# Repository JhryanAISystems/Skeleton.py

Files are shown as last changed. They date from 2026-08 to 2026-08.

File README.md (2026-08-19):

# Skeletonpy

Control software for an animatronic Halloween skeleton running on a Raspberry
Pi 4 Model B (4GB). It tracks faces with a camera, syncs the jaw to microphone
volume, switches between a calm "Host" and a jump-scare "Trickster"
personality, and speaks via pre-recorded lines and offline text-to-speech.

For the physical build (parts list, wiring, 3D-printed mounts, OS setup),
see [BUILD_GUIDE.md](BUILD_GUIDE.md). This README covers the software.

> **Note on hardware history:** this project originally targeted the
> Raspberry Pi Zero 2 W. Due to a prolonged supply shortage, the board was
> switched to a Pi 4 Model B (4GB). The Pi 4's larger footprint means it no
> longer fits inside the skull — it now lives in a separate torso/ribcage
> enclosure, connected to the skull's camera, servos, and LEDs by extended
> cables. The software stack is unchanged by this swap.

## How it works

`main.py` builds all hardware modules and wires them into a single
`BehaviorManager`, then runs a non-blocking control loop at
`CONFIG.timing.loop_hz` (~15 Hz):

1. `BehaviorManager.tick()` — polls triggers, updates head/jaw servo targets
   from vision/audio, and advances eye brightness.
2. `BehaviorManager.maybe_speak()` — occasionally queues a spoken line.

Every hardware-facing module (camera, mic/speaker, servos, LEDs, knock and
proximity sensors) follows the same pattern: a real backend using the actual
library (`picamera2`, `sounddevice`, `gpiozero`, ...), and a mock backend
that's auto-selected when the real one fails to import or initialize. This
means the exact same code runs on the Pi and on a dev laptop with no flags
or config changes.

### Personality state machine (`behavior.py`)

- **HOST** (default): amber, steady eyes; slower tracking/servo easing.
- **TRICKSTER**: red, flickering eyes; snappier tracking/servo easing.
- Switches to TRICKSTER on a loud noise, a knock, or someone getting within
  `CONFIG.proximity.trigger_distance_ft`. Auto-reverts to HOST after
  `CONFIG.timing.trickster_timeout_s` of no new triggers. A cooldown
  (`CONFIG.timing.mode_switch_cooldown_s`) prevents rapid re-triggering.

## Key files

| File | Responsibility |
|---|---|
| [main.py](main.py) | Entry point; builds the `BehaviorManager` and runs the control loop or `--test` smoke test |
| [behavior.py](behavior.py) | HOST/TRICKSTER state machine; knock and proximity sensor backends |
| [vision.py](vision.py) | Camera capture + Haar-cascade face tracking → head angle & closeness |
| [servo.py](servo.py) | Head/jaw servo control with eased (smoothed) motion |
| [audio.py](audio.py) | Mic amplitude sensing (jaw sync, loud-noise trigger) + non-blocking playback/TTS |
| [led.py](led.py) | Eye LED brightness, flicker, and Host/Trickster color state |
| [config.py](config.py) | All tunable parameters: GPIO pins, servo limits, thresholds, timing, audio line sets |
| [script_lines.py](script_lines.py) | Spoken-line content (guest lines, event lines, monologues) — kept separate from `config.py`. **Not tracked in this repo** — contains personalized guest content, kept local-only. |
| [generate_audio.py](generate_audio.py) | One-time offline script (run on a dev machine, not the Pi) that batch-generates MP3s via the ElevenLabs API from `script_lines.py` |
| `*.scad` | OpenSCAD source for 3D-printed mounts (see `BUILD_GUIDE.md` Part 4) |

## Setup

```bash
python3 -m venv venv
source venv/bin/activate      # Windows: venv\Scripts\activate
pip install -r requirements.txt
```

On a dev machine without Pi hardware, only `opencv-python` and `numpy` are
strictly required to run — everything else falls back to a mock backend if
its library or hardware isn't available.

## Usage

```bash
python main.py --test              # mock-hardware smoke test, then exit
python main.py                     # live run (real hardware where available)
python main.py --log-level DEBUG   # verbose logging
```

To (re)generate spoken-line audio from `script_lines.py`:

```bash
pip install requests
setx ELEVENLABS_API_KEY "your-key-here"   # Windows; reopen the shell after
python generate_audio.py
```

This writes MP3s into `audio/`, resuming safely if interrupted (existing
files are skipped). Copy the resulting `audio/` folder onto the Pi —
`audio.py` only plays files by name, it does not call the API on-device.

## Configuration

All tunables live in [config.py](config.py) as frozen dataclasses grouped by
subsystem (`GPIOPins`, `ServoLimits`, `AudioConfig`, `VisionConfig`,
`ProximityConfig`, `TimingConfig`, `AudioLineConfig`), bundled under the
module-level `CONFIG` singleton. Defaults were originally tuned for the Pi
Zero 2 W's limited CPU (smaller camera frame, frame-skipped detection,
slower loop rate). On the Pi 4, these are conservative rather than
necessary — there's headroom to raise camera resolution or loop rate if
you want a snappier feel, but the defaults are left as-is since they
already work reliably.

## Gotchas

- `main.py --test` reports in its log output which backend (real or mock)
  was selected for each module — if something you've wired up shows "mock",
  that's the first thing to check. Note that on a non-Pi dev machine (e.g.
  Windows), `picamera2` and `gpiozero` are *expected* to fall back to mock —
  that's the graceful-degradation design working as intended, not a bug.
- `generate_audio.py` is meant to run once, off-Pi, before deployment — not
  as part of the live control loop.
- Jittery head tracking or unreliable low-light detection are tuned via
  `tracking_smoothing_host` and `detection_min_neighbors` in `config.py`
  (see `BUILD_GUIDE.md` Part 5, steps 3 and 5).
- Since the Pi 4 lives in the torso rather than the skull, cable runs from
  skull to torso are longer than the original Pi Zero 2 W design assumed —
  see `BUILD_GUIDE.md` Part 2.8 for routing notes.

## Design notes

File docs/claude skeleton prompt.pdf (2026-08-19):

SYSTEM ROLE:
You are an expert robotics/embedded-systems engineer specializing in Raspberry Pi animatronics: OpenCV face tracking, audio amplitude detection, servo control,
LED PWM, and behavior-driven state machines.

TASK:
Generate a complete, runnable Python 3.11+ codebase for a full-size animatronic Halloween skeleton, split across the modules below. Output all files in one
response with clear file-path headers. No placeholders, no TODOs — every function must have working example logic (using mocked hardware where real hardware is unavailable).

──────────────────────────────
HARDWARE ASSUMPTIONS (state these as comments in config.py) ──────────────────────────────
- Raspberry Pi 4/5, Raspberry Pi Camera Module (picamera2)
- MG996R servo ×2 (head pan, jaw) via PWM (gpiozero or pigpio — pick one and use it consistently)
- USB microphone or I2S mic, read via sounddevice or pyaudio
- Common-cathode RGB or amber/red LED matrix for eyes, PWM-driven
- Optional: knock sensor (piezo/vibration) on a GPIO input pin, proximity sensor (e.g., HC-SR04 or VL53L0X) for the <2ft trigger
- Target 20–30 FPS control loop; assume no GPU acceleration

──────────────────────────────
MODULE SPECIFICATIONS
──────────────────────────────

config.py
- Dataclass or constants for: GPIO pin assignments (head servo, jaw servo, LED(s), knock sensor, proximity sensor), servo angle limits, audio RMS thresholds (ambient/loud-noise), face-tracking gain/smoothing constants, proximity threshold, mode-timeout duration, audio file paths, TTS voice params.

vision.py
- `FaceTracker` class: init Pi Camera (or `cv2.VideoCapture` fallback), Haar cascade or DNN face detection, compute horizontal pixel offset from frame center, convert to smoothed servo angle (exponential moving average), estimate relative distance from bounding-box size for LED brightness scaling.

audio.py
- `AudioInput` class: read mic amplitude (RMS) in a background thread, expose latest value non-blocking, map amplitude → jaw servo angle (linear or log-scaled), detect loud-noise threshold crossing (mode-switch trigger).

- `AudioOutput` class: non-blocking playback of pre-recorded WAV/MP3 (use `threading` or `asyncio` + a playback queue — pick one and justify briefly), and TTS generation/playback (pyttsx3 offline, with a stub for cloud TTS).

servo.py
- `ServoController` class: set angle with clamping, easing functions (e.g., ease-in-out) for smooth transitions, separate methods for head and jaw servos.
- Mock backend (prints/logs angle changes) auto-selected when `gpiozero`/RPi hardware isn't detected, so the whole system runs on a dev machine.

led.py
- `EyeController` class: PWM brightness control, flicker pattern generator (randomized or scripted), color switch between amber (Host) and red (Trickster).

behavior.py
- `BehaviorManager` state machine with two states: `HOST` and `TRICKSTER`.
- Constructed via dependency injection: takes `FaceTracker`, `AudioInput`, `AudioOutput`, `ServoController`, `EyeController` as constructor args (no internal instantiation).
- Trickster triggers: loud noise, knock sensor, proximity < 2ft.
- Auto-revert to Host after a configurable timeout of no triggers.
- Each mode has distinct: tracking smoothness, LED color/flicker profile, and a set of example line triggers (both pre-recorded file keys and TTS strings).

main.py
- Instantiate all modules (real or mock, auto-detected), inject into `BehaviorManager`, run a non-blocking main loop (fixed tick rate, no blocking calls) that: reads sensors → updates behavior state → updates servos/LEDs → fires audio as needed.
- Include a `--test` CLI flag that runs a short simulated session using mock hardware and asserts basic state transitions (simple test harness, not a full pytest suite unless you'd prefer one — default to a lightweight inline harness).

──────────────────────────────
CODING STANDARDS
──────────────────────────────
- Python 3.11+, full type hints, docstrings (Google or NumPy style, pick one)
on every public class/method.
- One hardware abstraction layer per module so real and mock backends share an interface (e.g., ABC or Protocol).
- No blocking sleeps in the main loop; use threading/asyncio for audio and
sensor polling.
- Comment every hardware-specific assumption inline, not just in config.py.

────────────────────────────── OUTPUT FORMAT
──────────────────────────────
1. Project tree first (brief).
2. Each file in full, separated by `# ===== path/filename.py =====` headers.
3. End with numbered setup/run instructions for actual Raspberry Pi deployment (dependencies, GPIO wiring notes, permissions, autostart).

Do not ask clarifying questions — resolve ambiguity using the defaults stated above and note any additional assumptions as a short bullet list at the very end.

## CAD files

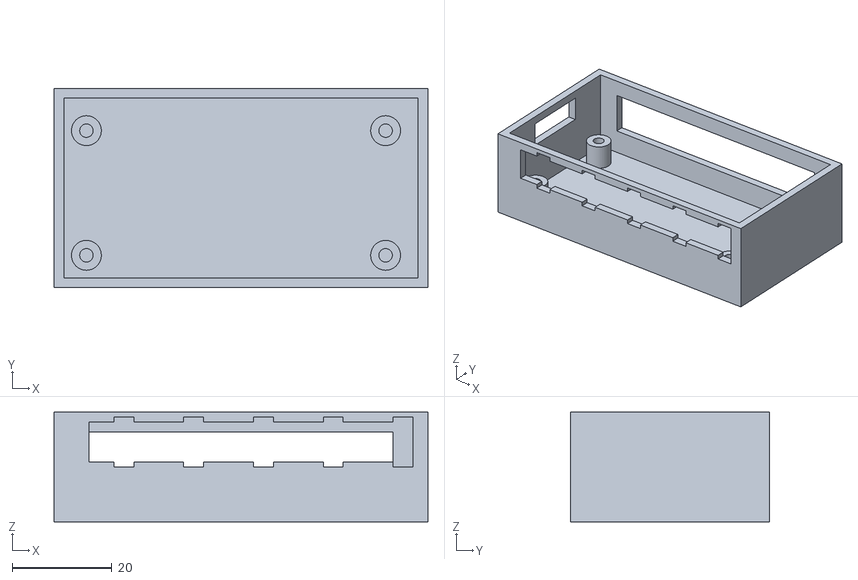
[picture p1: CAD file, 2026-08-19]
STL/electronics_enclosure.stl
75.0 x 40.0 x 22.0

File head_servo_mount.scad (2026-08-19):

// head_servo_mount.scad
//
// L-bracket that clamps an MG996R servo to a vertical spine rod (metal
// rod or 1/2" PVC pipe run up through the skeleton's spine) and provides
// a horn-to-neck-rod coupling on top.
//
// PRINT SETTINGS: PLA or PETG, 20% infill, 3 perimeters, no supports
// needed if printed with the spine-clamp face down.
//
// Render to STL: install OpenSCAD (openscad.org, free), open this file,
// press F6 to render, then File > Export > Export as STL.

// ---- Parameters (mm) — edit these to match your exact servo/rod ----
servo_body_l   = 40.7;   // MG996R body length
servo_body_w   = 20.2;   // MG996R body width
servo_body_h   = 38.0;   // MG996R body height (top of case to bottom, no horn)
servo_tab_l    = 54.7;   // outer length across the two mounting tabs
servo_tab_hole_spacing = 49.5; // distance between the two tab screw holes
tab_hole_d     = 3.2;    // M3 screw clearance

spine_rod_od   = 12.7;   // 1/2" PVC OD ≈ 12.7mm; use your rod's actual OD
neck_rod_od    = 6.0;    // dowel/rod inserted into the skull

wall = 3.5;              // bracket wall thickness
clamp_gap = 2.0;         // slot width that lets the clamp flex closed

$fn = 60;

module servo_cutout() {
    // Pocket that the servo body drops into, open on top for the horn shaft.
    translate([-servo_body_l/2, -servo_body_w/2, 0])
        cube([servo_body_l, servo_body_w, servo_body_h + 1]);
}

module tab_holes() {
    for (x = [-servo_tab_hole_spacing/2, servo_tab_hole_spacing/2])
        translate([x, 0, -1])
            cylinder(h = wall*2 + 2, d = tab_hole_d);
}

module spine_clamp() {
    // A split ring that clamps around the vertical spine rod. Two ears
    // with holes let you cinch it tight with a small M3 bolt + nut, or
    // just zip-tie through them if you'd rather not tap threads.
    outer_d = spine_rod_od + wall*2;
    difference() {
        union() {
            cylinder(h = 25, d = outer_d);
            // clamp ears
            for (side = [-1, 1])
                translate([side * (outer_d/2 - 1), -6, 0])
                    cube([10, 12, 25]);
        }
        translate([0, 0, -1]) cylinder(h = 27, d = spine_rod_od);
        // the slot that lets the ring flex closed around the rod
        translate([-clamp_gap/2, 0, -1]) cube([clamp_gap, outer_d, 27]);
        // ear bolt holes
        for (side = [-1, 1])
            translate([side * (outer_d/2 + 4), 0, 12.5])
                rotate([90,0,0]) cylinder(h = 20, d = 3.2, center = true);
    }
}

module servo_platform() {
    // Flat plate on top of the spine clamp that the servo sits on,
    // secured through its mounting tabs.
    plate_l = servo_tab_l + 6;
    plate_w = servo_body_w + wall*2;
    plate_h = wall;

    difference() {
        translate([-plate_l/2, -plate_w/2, 0])
            cube([plate_l, plate_w, plate_h]);
        translate([0, 0, plate_h/2])
            servo_cutout();
        translate([0, 0, plate_h/2])
            tab_holes();
    }
}

module neck_rod_collar() {
    // Sits on the servo horn (glue or horn-screw through the center hole)
    // and grips the rod that runs up into the skull.
    difference() {
        cylinder(h = 15, d = neck_rod_od + wall*2);
        translate([0,0,-1]) cylinder(h = 17, d = neck_rod_od);
        // set-screw hole to pin the rod in place
        translate([0, 0, 8]) rotate([90,0,0])
            cylinder(h = neck_rod_od + wall*2 + 2, d = 2.5, center = true);
    }
}

// ---- Assembly (printed as separate pieces, positioned here for preview) ----
spine_clamp();
translate([0, 0, 25]) servo_platform();
translate([40, 0, 0]) neck_rod_collar();

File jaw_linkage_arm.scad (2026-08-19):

// jaw_linkage_arm.scad
//
// A rigid extension arm connecting the jaw servo's horn to the skull's
// jaw hinge pin, so the servo (mounted inside the upper skull) can pull
// the jaw open/closed as it rotates.
//
// PRINT SETTINGS: PLA or PETG, 100% infill (this part takes repeated
// mechanical stress — don't skimp on infill here), no supports needed.

arm_length   = 32;   // horn-pivot to jaw-pivot distance — measure your skull
arm_width    = 8;
arm_thick    = 4;

horn_hole_d  = 2.0;   // standard servo horn screw-hole diameter
jaw_pin_d    = 3.0;   // diameter of the pin/pivot you'll use at the jaw end

horn_circle_d = 24;   // MG996R horn diameter, for the mounting pattern
$fn = 40;

module arm() {
    difference() {
        union() {
            // main arm body, rounded ends
            hull() {
                translate([0, 0, 0]) cylinder(h = arm_thick, d = arm_width);
                translate([arm_length, 0, 0]) cylinder(h = arm_thick, d = arm_width);
            }
        }
        // horn-side mounting holes (screw straight into a servo horn arm,
        // or drill out to match your specific horn's hole pattern)
        translate([0, 0, -1]) cylinder(h = arm_thick + 2, d = horn_hole_d);
        for (a = [0:90:270])
            rotate([0, 0, a])
                translate([horn_circle_d/2, 0, -1])
                    cylinder(h = arm_thick + 2, d = horn_hole_d);
        // jaw-pivot hole at the far end
        translate([arm_length, 0, -1]) cylinder(h = arm_thick + 2, d = jaw_pin_d);
    }
}

arm();

// Reminder: rubber-dampen the jaw pivot end (a short piece of silicone
// tubing over the pin) so the jaw doesn't clack loudly against the skull
// on every closure — the original build guide's "add rubber dampers" step
// still applies here, just at this specific joint.

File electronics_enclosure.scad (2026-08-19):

// electronics_enclosure.scad
//
// A ventilated box sized for the Raspberry Pi Zero 2 W plus its wiring,
// meant to sit inside the ribcage. Standoffs match the Zero's mounting
// holes; slots on the sides let servo/LED/sensor wires and the USB audio
// dongle pass through without needing extra drilled holes later.
//
// PRINT SETTINGS: PLA or PETG, 20% infill, supports needed only for the
// standoffs' overhang if you print in one piece — or print the lid
// separately (recommended) to avoid supports entirely.

// Pi Zero 2 W board: 65mm x 30mm, mounting holes 3.5mm from each edge corner
board_l = 65.0;
board_w = 30.0;
hole_inset = 3.5;
hole_d = 2.7;          // clearance for M2.5 standoffs/screws

wall = 2.0;
box_h = 22.0;           // interior clearance above the board for the camera
                         // ribbon connector and GPIO header
lid_h = 3.0;

standoff_od = 6.0;
standoff_h  = 6.0;      // lifts the board off the floor for wire clearance

$fn = 40;

module standoff(x, y) {
    translate([x, y, wall])
        difference() {
            cylinder(h = standoff_h, d = standoff_od);
            translate([0,0,-1]) cylinder(h = standoff_h+2, d = hole_d);
        }
}

module box_body() {
    outer_l = board_l + wall*2 + 6;
    outer_w = board_w + wall*2 + 6;

    difference() {
        cube([outer_l, outer_w, box_h]);
        translate([wall, wall, wall])
            cube([outer_l - wall*2, outer_w - wall*2, box_h]);

        // GPIO header access slot along one long edge (ribbon or jumper
        // wires exit here toward the servos/LEDs/sensors)
        translate([wall + 5, -1, box_h - 10])
            cube([outer_l - wall*2 - 10, wall + 2, 8]);

        // USB audio dongle + micro-USB power cable exit slot, opposite edge
        translate([wall + 5, outer_w - wall - 1, box_h - 14])
            cube([outer_l - wall*2 - 10, wall + 2, 10]);

        // camera ribbon exit slot, short edge
        translate([-1, outer_w/2 - 8, box_h - 8])
            cube([wall + 2, 16, 6]);

        // ventilation slots on the lid-facing top rim (simple slits)
        for (i = [0:5])
            translate([12 + i*14, -1, box_h/2])
                cube([4, wall+2, 10]);
    }

    standoff(hole_inset + 3, hole_inset + 3);
    standoff(outer_l - wall - hole_inset - 3, hole_inset + 3);
    standoff(hole_inset + 3, outer_w - wall - hole_inset - 3);
    standoff(outer_l - wall - hole_inset - 3, outer_w - wall - hole_inset - 3);
}

box_body();

// Print a matching flat lid separately:
//   cube([outer_l, outer_w, lid_h])
// sized to friction-fit or be held with two small screws into the two
// standoffs nearest the lid opening — adjust to taste, this enclosure is
// deliberately simple so it's easy to modify.

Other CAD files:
eye_led_diffuser.scad
eye_socket_camera_mount.scad

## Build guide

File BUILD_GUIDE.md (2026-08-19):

# 💀 BUILD GUIDE — Animatronic Skeleton on Raspberry Pi 4 Model B

*Written for a first-time hobbyist. If you've never soldered, wired a
breadboard, or flashed an SD card before, you can still do this — every
step says exactly what to do and why. Budget a full weekend for the first
build.*

> **Hardware history note:** this project originally targeted the
> Raspberry Pi Zero 2 W, chosen because it's small enough to sit inside the
> skull alongside the camera and servos. Due to a prolonged supply
> shortage, the board was switched to a **Pi 4 Model B (4GB)**. The Pi 4 is
> roughly triple the footprint of the Zero 2 W and does **not** fit in the
> skull — it now lives in a separate enclosure in the torso/ribcage, with
> the camera, servos, and LEDs remaining in the skull and connected back to
> the Pi 4 via extended cables. This guide reflects that split. If you
> manage to source a Zero 2 W later, the skull-only layout still works —
> just skip the torso enclosure section.

---

## Before you start: what this build does and doesn't do

- ✅ Real camera-based face tracking (OpenCV Haar-cascade detection)
- ✅ Head servo turns to follow whoever it detects
- ✅ Jaw synced live to microphone volume
- ✅ Two personality modes (calm "Host" / jump-scare "Trickster")
- ✅ Mode switches on loud noise, a knock, or someone getting close
- ✅ Pre-recorded voice lines + offline text-to-speech
- ℹ️ The Pi 4 has plenty of headroom for this workload — the original
  performance-tuning notes in `config.py` (smaller camera resolution,
  frame-skipping, slower loop rate) were written for the much weaker Zero
  2 W. They're left as conservative defaults; you can raise resolution or
  loop rate if you want a snappier feel, but they aren't required for the
  Pi 4 to run smoothly.

---

## Part 1 — Shopping list

Prices are approximate USD, checked against current retailer listings;
shop around and expect some drift.

### Electronics

| Item | Qty | Approx. price | Notes |
|---|---|---|---|
| Raspberry Pi 4 Model B (4GB) | 1 | ~$100 | Price reflects ongoing shortage-driven inflation across the Pi lineup (MSRP was $55) — check availability before ordering |
| Raspberry Pi 15W USB-C Power Supply (5.1V/3A) | 1 | ~$9 | Pi 4–specific. Do **not** use the 27W supply — that's for Pi 5 |
| microSD card, 32GB, A2/V30 (official Raspberry Pi brand recommended) | 1 | ~$20 | Get the version pre-loaded with Raspberry Pi OS if available — saves an imaging step |
| Raspberry Pi Camera Module 3 (Standard) | 1 | ~$29 | Ships with a **standard CSI cable** — this plugs directly into the Pi 4, no adapter needed. (This is a change from the Zero 2 W, which needed a separate narrow-CSI adapter cable — don't buy that one.) |
| MG996R servo | 2 | $6 each | One for head rotation, one for the jaw |
| USB audio adapter (mic-in + headphone-out combo) | 1 | $6 | Pi 4 does have a 3.5mm jack, but a USB audio dongle is still recommended for cleaner mic input |
| Small powered speaker or amplified 3.5mm speaker | 1 | $8 | Plugs into the audio dongle's headphone jack (or the Pi 4's onboard jack) |
| High-brightness LEDs (amber, red, or bi-color) | 2 | $1 each | Eyes — only need 1 if you're putting the camera in the other socket |
| 220Ω resistors | 2 | <$1 | Current-limiting for the LEDs |
| Piezo disc or small vibration sensor | 1 | $2 | Knock sensor |
| HC-SR04 ultrasonic distance sensor | 1 | $3 | Proximity trigger |
| Logic-level shifter (or 1kΩ + 2kΩ resistor pair) | 1 | $2 | HC-SR04's ECHO pin outputs 5V; the Pi's GPIO is 3.3V-only |
| Female-to-female jumper wires (pack) | 1 | $5 | For sensor/LED wiring |
| Male-to-female jumper wires (pack) | 1 | $5 | For servo wiring |
| **Extension wire / ribbon cable for skull-to-torso runs** | — | ~$5–10 | Not needed on the original skull-only Zero 2 W layout — now required to run servo, LED, and camera signal from the skull down to the torso-mounted Pi 4. Length depends on your prop's height. |
| 4×AA battery holder + switch (6V) **or** a 6V 2A wall adapter | 1 | ~$3–10 | **Dedicated servo power** — never power servos from the Pi's 5V rail |
| Small proto-board or terminal block | 1 | $3 | Optional, makes wiring tidier than loose jumpers |

**Electronics subtotal: roughly $195–210** (higher than the original Zero 2 W estimate, mostly due to the pricier board and added cable runs)

### 3D-printed parts (see Part 4) — or substitute materials

| Item | Qty | Notes |
|---|---|---|
| PLA filament (standard color) | ~150g | Servo mounts, jaw linkage, skull-side enclosures |
| PLA filament, **translucent/natural** | ~30g | Eye diffuser dome only — needs to glow, not print opaque |
| PLA/PETG filament (standard color) | ~100g | **New**: torso enclosure for the Pi 4 — larger than the original skull-only enclosure |
| Small M3 bolts + nuts | ~8 | Spine clamp and mount assembly |
| M2.5 standoffs or small self-tapping screws | 4 | Mounting the Pi board in its enclosure |

*No printer? See "No 3D printer?" at the end of Part 4 for a buy-instead
alternative for every printed part.*

### Structure and props

| Item | Qty | Notes |
|---|---|---|
| Full-size plastic prop skeleton | 1 | Any Halloween-decor skeleton with a detachable head/skull works |
| Metal rod or ½" PVC pipe, ~4ft | 1 | Spine reinforcement — also doubles as a cable channel from skull to torso now |
| Wooden dowel or metal rod, ~6" | 1 | Neck rotation shaft (goes servo → skull) |
| Short length of silicone tubing | ~1" | Dampens the jaw pivot so it doesn't clack |
| Zip ties | 1 pack | Cable management + neck reinforcement |
| Stand or wall bracket | 1 | However you're mounting the finished prop |

---

## Part 2 — Physical assembly

### 2.1 Reinforce the skeleton

1. Run the metal rod or PVC pipe up through the spine to eliminate wobble. With the Pi 4 now living in the torso rather than the skull, this same channel will also carry your servo/LED/camera extension cables down to the torso enclosure — worth keeping that in mind as you route it.
2. Zip-tie or screw it to the ribcage/pelvis mounting points your prop skeleton has.
3. Mount the reinforced skeleton on its stand or wall bracket now — it's much easier to work on upright.

### 2.2 Head servo + neck rotation

1. Print `head_servo_mount.scad` (see Part 4) — this gives you a spine clamp, a servo platform, and a neck-rod collar.
2. Clamp the spine-clamp piece around your spine rod at the top, just below where the neck meets the skull, and bolt or zip-tie it snug (it has a flex-slot for this).
3. Screw the MG996R into the servo platform using its mounting tabs, then attach the platform on top of the clamp.
4. Push your neck dowel/rod into the skull's neck opening (glue if it's loose) and attach the other end to the printed neck-rod collar.
5. Slide the collar onto the servo horn and secure with the horn's screw, at the servo's **center (90°) position** — this becomes your head's forward-facing center.
6. Reattach the skull. Manually rotate the servo horn (unpowered) through its range to confirm the head turns freely without binding on wires or the ribcage.

### 2.3 Jaw servo

1. Open the skull if it's detachable, or work through the mouth opening if not.
2. Mount the second MG996R inside the upper skull using screws or strong epoxy, positioned so its horn is near the jaw hinge.
3. Print `jaw_linkage_arm.scad`, measuring your actual horn-to-jaw-pivot distance first and editing the `arm_length` variable at the top of the file before rendering.
4. Screw the arm to the servo horn, and thread the silicone tubing over the jaw-pivot pin before connecting the arm's other end — this is your rubber damper, so the jaw doesn't clack loudly on every closure.
5. Manually cycle the jaw through open/closed (servo unpowered) to confirm it doesn't bind.

### 2.4 Camera in one eye socket

1. Print `eye_socket_camera_mount.scad`, measuring your skull's actual eye socket diameter first (edit `socket_od`).
2. Seat the Camera Module into the printed ring — it should snap/friction-fit against the pocket.
3. Route the CSI ribbon cable back through the skull and down the spine toward the torso enclosure. **Be gentle** — these ribbons crease permanently if bent sharply. Since the Pi 4 is now in the torso rather than right there in the skull, this run is considerably longer than the original design — if the stock cable that shipped with the Camera Module 3 doesn't reach, you'll need a longer CSI extension cable (available from the same retailers).
4. Glue or press-fit the ring into the eye socket, angled *very slightly* downward — visitors are usually shorter than the skeleton's natural eye line.

### 2.5 LED eye

1. Print `eye_led_diffuser.scad` in **translucent** filament — this is the one part where filament color matters functionally, not just aesthetically.
2. Wire your LED with its 220Ω resistor (resistor in series on the positive leg), thread the leads through the diffuser's base hole, and seat the LED inside the dome.
3. Press-fit or glue the diffuser into the remaining eye socket.

### 2.6 Microphone and speaker

1. Mount the USB audio dongle somewhere accessible — behind the ribcage or teeth works, since you'll want to reach it if you ever need to re-seat the USB connection.
2. Route a short USB extension down to where the Pi 4 will live in the torso enclosure.
3. Mount the small speaker inside the ribcage, plugged into the dongle's headphone-out jack.

### 2.7 Knock sensor and proximity sensor

1. Mount the piezo/vibration sensor on the door frame or wherever visitors will actually knock or brush against.
2. Mount the HC-SR04 facing the approach path to your entrance — usually at chest height on the prop itself, or on a nearby post.
3. **Wire the HC-SR04's ECHO pin through your logic-level shifter (or the 1kΩ/2kΩ resistor divider)** before it reaches the Pi's GPIO — skipping this step risks damaging the GPIO pin, since the sensor outputs 5V and the Pi's inputs are 3.3V only.

### 2.8 Electronics enclosure and power — Pi 4 torso layout

This section changed the most from the original Zero 2 W design.

1. Print a torso-sized enclosure sized for the Pi 4's larger board (roughly
   85×56mm plus standoff clearance and airflow — the original
   `electronics_enclosure.scad` was sized for the much smaller Zero 2 W and
   will need to be re-scaled or redesigned; see Part 4 note).
2. Mount the Pi 4 inside on the four standoffs, in the torso/ribcage
   cavity rather than the skull.
3. Bring all your skull-side wiring — head servo, jaw servo, both LEDs,
   knock sensor, HC-SR04 — down through the spine channel to reach the
   Pi 4's GPIO header in the torso. Connect per the pin table (GPIO17 head
   servo, GPIO27 jaw servo, GPIO22/23 eyes, GPIO24 knock, GPIO5/6 HC-SR04).
4. **Power split — this is the step people most often get wrong:**
   - The Pi 4 gets its own **5.1V/3A USB-C** supply into its USB-C power
     port. This is a higher current requirement than the Zero 2 W's
     5V/2.5A micro-USB supply — make sure you're using the Pi 4–specific
     15W USB-C supply, not the old micro-USB one.
   - The two servos get power from the **separate** 6V battery pack or
     wall adapter — never from the Pi's 5V rail. MG996R servos can draw
     well over an amp each under load; the Pi cannot supply that safely.
     This rule is unchanged by the board swap.
   - **Tie the grounds together**: run a wire from the servo power
     supply's ground/negative to any GPIO ground pin on the Pi. Without
     this shared ground, your PWM signals won't have a stable reference
     and servo motion will be erratic.
5. Mount the enclosure inside the ribcage/torso cavity, with the GPIO
   header facing where your servo/LED/sensor wiring runs down from the
   skull, and the USB-C power port accessible for the wall supply.

---

## Part 3 — Software setup

Unchanged from the original design — the Pi 4 runs the same OS and same
codebase as the Zero 2 W would have.

### 3.1 Flash the OS

1. Download **Raspberry Pi Imager** (free, from raspberrypi.com/software) on your regular computer.
2. Insert the microSD card.
3. In Imager, choose **Raspberry Pi OS Lite (64-bit)** — you don't need the desktop environment, and Lite leaves more RAM free for your code.
4. Click the gear icon (⚙) before writing: set your hostname, enable SSH, set a username/password, and pre-configure your Wi-Fi credentials. This lets you boot the Pi headless — no monitor/keyboard needed.
5. Write the image, then boot the Pi with the SD card inserted.

### 3.2 First boot and enabling the camera

```bash
ssh yourusername@yourhostname.local
sudo raspi-config
```

In `raspi-config`:
- **Interface Options → Camera → Enable**
- **System Options → Audio → select the USB audio device** as the output
- Reboot when prompted.

### 3.3 Install system dependencies

```bash
sudo apt update
sudo apt install -y python3-venv portaudio19-dev python3-pyaudio espeak libespeak1 pigpio
sudo systemctl enable pigpiod
sudo systemctl start pigpiod
```

### 3.4 Get the code onto the Pi and install Python packages

Copy the `Skeletonpy/` project folder onto the Pi (via `scp`, a USB
drive, or `git clone` from the repo), then:

```bash
cd Skeletonpy
python3 -m venv venv
source venv/bin/activate
pip install -r requirements.txt
```

This installs opencv-python, numpy, picamera2, gpiozero, pigpio,
sounddevice, simpleaudio, playsound, and pyttsx3.

> Note: `script_lines.py` is not tracked in the git repo (it contains
> personalized guest content). Copy it onto the Pi separately — USB drive
> or `scp` — after cloning, or `main.py` will fail to import it.

### 3.5 Add your audio lines

Place WAV/MP3 files under `assets/audio/` matching the filenames listed in
`config.py`'s `AudioLineConfig` — e.g. `assets/audio/host_greeting_01.wav`.
Record these yourself, or edit the filenames in `config.py` to match
whatever clips you already have.

### 3.6 Run it

```bash
python main.py --test     # mock-hardware smoke test — confirms the code runs at all
python main.py            # live run with real camera/servos/sensors
```

---

## Part 4 — 3D printed parts

All files are plain-text **OpenSCAD** source (`.scad`), not binary
STL — this is deliberate: OpenSCAD is free, and having the source means
you can tweak a single number (a servo dimension, a socket diameter) and
re-render, instead of hand-editing a mesh.

**To turn these into files your printer's slicer understands:**
1. Install OpenSCAD (openscad.org — free, all platforms).
2. Open each `.scad` file.
3. Press **F5** to preview, **F6** to fully render.
4. **File → Export → Export as STL.**
5. Open the resulting `.stl` in your slicer (PrusaSlicer, Cura, whatever came with your printer) as usual.

| File | What it makes | Filament note |
|---|---|---|
| `head_servo_mount.scad` | Spine clamp + servo platform + neck-rod collar | Standard PLA |
| `jaw_linkage_arm.scad` | Servo-horn-to-jaw-pivot linkage | **100% infill** — this part takes repeated stress |
| `eye_socket_camera_mount.scad` | Snap-fit ring holding the camera in one eye socket | Standard PLA |
| `eye_led_diffuser.scad` | Glowing dome for the LED eye | **Translucent/natural PLA only** |
| `electronics_enclosure.scad` | ⚠️ **Needs updating for this pivot.** Currently sized for the Pi Zero 2 W's much smaller footprint (65×30mm) — the Pi 4 (85×56mm) will not fit as-is. Either rescale the dimensions in this file before printing, or treat it as a reference/placeholder until a torso-specific enclosure is designed. | Standard PLA/PETG |

**Before rendering, open each file and check the parameter block at the
top** — servo dimensions, rod diameters, and socket sizes are variables
you should measure against your own parts, not assume match mine exactly.

### No 3D printer?

Every part has a low-tech substitute:
- **Head servo mount**: a metal servo bracket (sold for hobby servos, ~$5) zip-tied to the spine rod, with the neck dowel epoxied directly to the servo horn.
- **Jaw linkage**: a straight servo horn extension arm (comes with most servos) bent/drilled to reach the jaw pivot.
- **Camera mount**: hot glue and patience — friction-fit the camera board directly into the eye socket.
- **LED diffuser**: a ping-pong ball half, sanded from the inside, hot-glued into the socket.
- **Electronics enclosure (torso)**: any small plastic project box large enough for the Pi 4 (roughly 90×60×30mm minimum), with holes drilled for cable pass-through and the USB-C power port.

---

## Part 5 — Testing sequence

1. `python main.py --test` — confirms the state machine and mode-switching logic all pass, and tells you (in the log output) which backends — real or mock — got selected for each module. If it says "mock" for something you've wired up, that's your first debugging clue. (On a non-Pi dev machine, `picamera2`/`gpiozero` mock fallback is expected, not a bug.)
2. Power on and confirm `raspistill`/the camera preview works before trusting `main.py`'s face tracking. Since the camera cable now runs a longer distance from skull to torso, this is also your first check that the extended CSI run didn't degrade the signal.
3. Confirm head tracking follows a face smoothly in Host mode. If it's jittery, increase `tracking_smoothing_host` in `config.py` (lower = smoother).
4. Confirm jaw sync reacts to speech/noise.
5. Confirm eye glow and, separately, camera image quality in your actual lighting conditions (Halloween decorating is usually dim — you may need to lower `detection_min_neighbors` in `VisionConfig` for reliable detection in low light).
6. Trigger Trickster mode three ways — loud noise, knock, close proximity — confirming each independently.
7. Confirm auto-revert to Host after ~20 seconds of quiet.
8. Confirm both pre-recorded lines and TTS play through the speaker.
9. Let the full loop run for at least 30 minutes and watch for slowdown. On the Pi 4 this is less likely to be a CPU/thermal issue than it was on the Zero 2 W, but it's still worth confirming — particularly that the longer skull-to-torso cable runs aren't introducing any intermittent connection issues under sustained vibration/movement.

---

## Part 6 — Optional enhancements

- Fog machine triggered by proximity (add a relay + fog machine, hook into `behavior.py`'s `_check_triggers`)
- A second HC-SR04 or a PIR sensor for wider approach detection
- Face *recognition* (not just detection) — swap the Haar cascade in `vision.py` for LBPH-based recognition (`opencv-contrib-python`) if you want it to react differently to specific known faces vs. strangers. The Pi 4 has comfortable headroom for this; it would have been noticeably heavier on the original Zero 2 W target.
- Additional pan/tilt axes for more expressive head movement — mechanically more involved than the single head-rotation servo above, but the Pi 4's GPIO and processing headroom both support it if you want to take the build further.

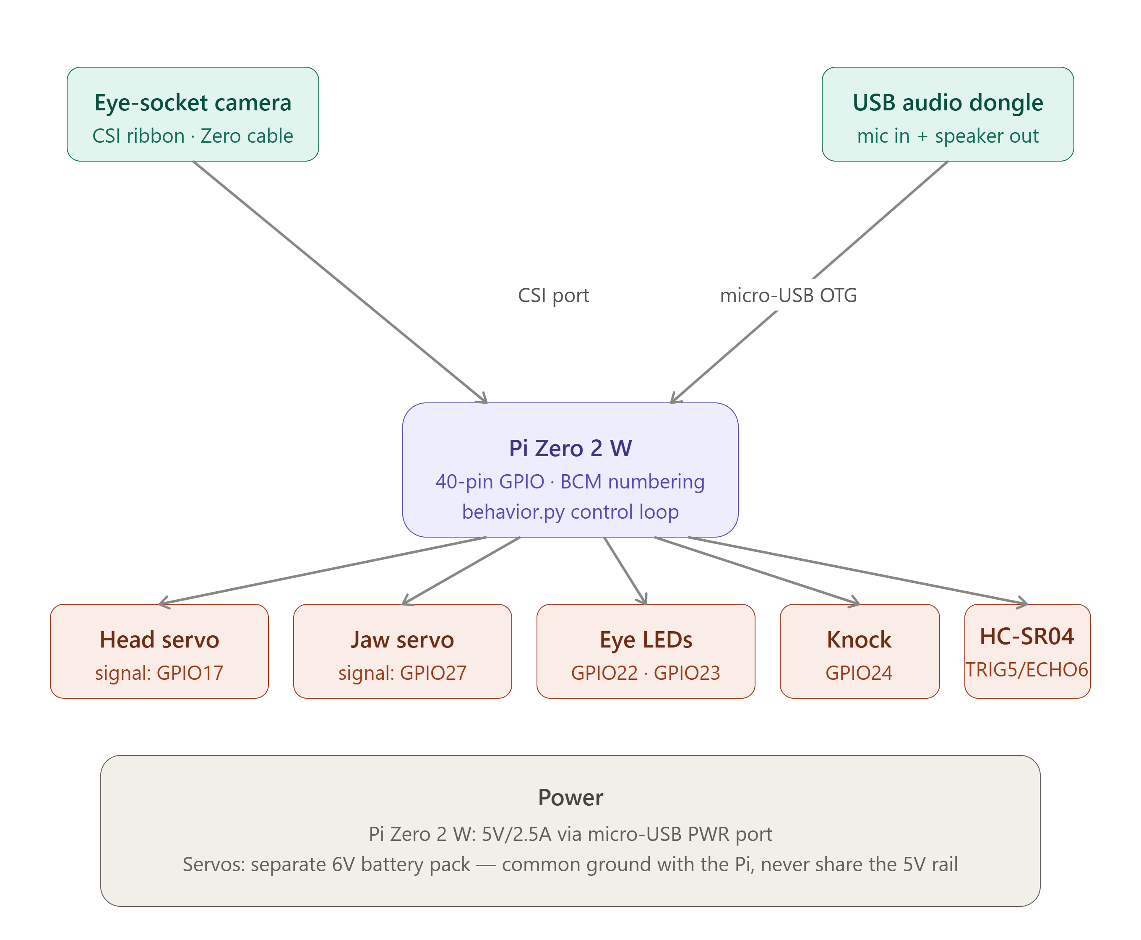
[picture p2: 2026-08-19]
docs/pi_zero2w_skeleton_wiring.png

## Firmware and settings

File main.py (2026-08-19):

"""
main.py

Entry point for the animatronic skeleton system. Initializes all hardware
modules (real backends on a Pi, mock backends elsewhere), wires them into
`BehaviorManager` via dependency injection, and runs the main control loop.

Usage:
    python main.py            # run the live control loop
    python main.py --test     # run a short simulated session on mock hardware
"""

from __future__ import annotations

import argparse
import logging
import random
import time

from audio import AudioInput, AudioOutput
from behavior import BehaviorManager, Mode, MockKnockSensorBackend, MockProximitySensorBackend
from config import CONFIG
from led import EyeController
from servo import ServoController
from vision import FaceTracker

logger = logging.getLogger(__name__)


def make_guest_greeting_callback(audio_out: AudioOutput):
    """Build the `on_guest_recognized` callback passed to `BehaviorManager`.

    This is the one place that bridges recognition (guest key, generic)
    to actual dialogue content (`script_lines.py`, personal/private —
    not tracked in this repo, see .gitignore). Import is deferred and
    wrapped so the system degrades gracefully if `script_lines.py` isn't
    present on this machine (e.g. a fresh clone before it's been copied
    over separately, per BUILD_GUIDE.md).

    NOTE: this assumes `script_lines.py` exposes a `GUESTS` dict shaped
    roughly like:
        GUESTS = {
            "guest_key": {
                "display_name": "...",
                "lines": [{"text": "..."}, ...],
            },
            ...
        }
    Adjust the lookup below if your actual structure differs.
    """

    def _on_guest_recognized(guest_key: str) -> None:
        try:
            from script_lines import GUESTS  # type: ignore
        except ImportError:
            logger.debug(
                "script_lines.py not found; skipping personalized greeting "
                "for guest '%s'", guest_key,
            )
            return

        guest = GUESTS.get(guest_key)
        if not guest:
            logger.debug("Guest key '%s' not found in script_lines.GUESTS", guest_key)
            return

        lines = guest.get("lines") or []
        if not lines:
            return

        choice = random.choice(lines)
        text = choice.get("text") if isinstance(choice, dict) else str(choice)
        if text:
            audio_out.speak_text(text)

    return _on_guest_recognized


def build_behavior_manager() -> BehaviorManager:
    """Construct all hardware modules and inject them into a BehaviorManager.

    Each module auto-detects real vs. mock hardware internally, so this
    function works unmodified both on a Raspberry Pi and on a dev laptop.
    """
    vision = FaceTracker()
    audio_in = AudioInput()
    audio_out = AudioOutput()
    servos = ServoController()
    eyes = EyeController()

    return BehaviorManager(
        vision=vision,
        audio_in=audio_in,
        audio_out=audio_out,
        servos=servos,
        eyes=eyes,
        on_guest_recognized=make_guest_greeting_callback(audio_out),
    )


def run_main_loop(manager: BehaviorManager) -> None:
    """Run the non-blocking control loop at the configured tick rate.

    The loop itself contains no blocking calls: vision reads a single
    already-captured frame, audio amplitude is read from a background
    thread's latest value, and audio playback/TTS are queued onto a
    separate worker thread. Only a short `time.sleep` is used to hold the
    loop to its target rate, which is standard practice for a fixed-tick
    control loop (as opposed to blocking on I/O).
    """
    tick_period = 1.0 / CONFIG.timing.loop_hz
    logger.info("Starting main control loop at %.1f Hz", CONFIG.timing.loop_hz)

    try:
        while True:
            loop_start = time.monotonic()

            manager.tick()
            manager.maybe_speak()

            elapsed = time.monotonic() - loop_start
            sleep_time = max(0.0, tick_period - elapsed)
            time.sleep(sleep_time)
    except KeyboardInterrupt:
        logger.info("Shutdown requested (Ctrl+C).")


def run_test_harness() -> None:
    """Lightweight inline smoke test using fully mocked hardware.

    Verifies:
      1. The system initializes without error (including the new tilt
         servo and recognizer backend detection).
      2. A knock event correctly triggers a switch to TRICKSTER mode.
      3. A number of ticks run cleanly without exceptions in TRICKSTER mode.
      4. Mode reverts to HOST once the trickster timeout window would have
         elapsed (simulated by directly manipulating the manager's timer).

    This is intentionally lightweight rather than a full pytest suite, per
    the project spec's request for "a simple test harness in main.py".
    """
    logging.basicConfig(level=logging.INFO)
    logger.info("=== Running test harness (mock hardware) ===")

    vision = FaceTracker()
    audio_in = AudioInput()
    audio_out = AudioOutput()
    servos = ServoController()
    eyes = EyeController()
    knock = MockKnockSensorBackend()
    proximity = MockProximitySensorBackend()

    manager = BehaviorManager(
        vision=vision,
        audio_in=audio_in,
        audio_out=audio_out,
        servos=servos,
        eyes=eyes,
        knock_sensor=knock,
        proximity_sensor=proximity,
        on_guest_recognized=make_guest_greeting_callback(audio_out),
    )

    assert manager.mode == Mode.HOST, "Should start in HOST mode"
    logger.info("PASS: initial mode is HOST")

    for _ in range(5):
        manager.tick()
    logger.info("PASS: ticks run cleanly with pan/tilt + recognition wired in")

    knock.simulate_knock()
    manager.tick()
    assert manager.mode == Mode.TRICKSTER, "Knock should trigger TRICKSTER mode"
    logger.info("PASS: knock event switched mode to TRICKSTER")

    for _ in range(10):
        manager.tick()
    assert manager.mode == Mode.TRICKSTER, "Should remain TRICKSTER before timeout"
    logger.info("PASS: mode remains TRICKSTER before timeout elapses")

    # Simulate timeout elapsing without touching private state directly
    # from outside the class in production code -- acceptable here since
    # this is a same-module test harness exercising internal behavior.
    manager._last_trigger_time -= CONFIG.timing.trickster_timeout_s + 1.0  # noqa: SLF001
    manager._last_mode_switch_time = 0.0  # noqa: SLF001
    manager.tick()
    assert manager.mode == Mode.HOST, "Mode should revert to HOST after timeout"
    logger.info("PASS: mode reverted to HOST after timeout")

    servos.shutdown()
    eyes.shutdown()
    audio_in.shutdown()
    audio_out.shutdown()
    vision.close()

    logger.info("=== All test harness checks passed ===")


def main() -> None:
    parser = argparse.ArgumentParser(description="Animatronic skeleton control system")
    parser.add_argument(
        "--test",
        action="store_true",
        help="Run a short simulated session on mock hardware and exit.",
    )
    parser.add_argument(
        "--log-level",
        default="INFO",
        choices=["DEBUG", "INFO", "WARNING", "ERROR"],
        help="Logging verbosity.",
    )
    args = parser.parse_args()

    logging.basicConfig(
        level=getattr(logging, args.log_level),
        format="%(asctime)s [%(levelname)s] %(name)s: %(message)s",
    )

    if args.test:
        run_test_harness()
        return

    manager = build_behavior_manager()
    run_main_loop(manager)


if __name__ == "__main__":
    main()

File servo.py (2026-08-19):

"""
servo.py

Pan, tilt, and jaw servo control, with software easing for smooth motion.

Hardware assumption: three MG996R servos driven via PWM. On a real Pi this
uses `gpiozero.AngularServo` (which itself typically rides on the `pigpio`
pin factory for jitter-free PWM). When `gpiozero`/GPIO hardware isn't
available (e.g., developing on a laptop), a `MockServoBackend` is used
instead so the rest of the system runs unmodified.
"""

from __future__ import annotations

import logging
from abc import ABC, abstractmethod
from typing import Protocol

from config import CONFIG

logger = logging.getLogger(__name__)


class ServoBackend(Protocol):
    """Hardware abstraction that any servo backend must implement."""

    def set_angle(self, pin: int, angle_deg: float) -> None:
        """Drive the servo on `pin` to `angle_deg` immediately (no easing)."""
        ...

    def close(self) -> None:
        """Release hardware resources."""
        ...


class MockServoBackend:
    """Logs servo commands instead of driving real hardware.

    Auto-selected on any machine without `gpiozero` + GPIO access, so the
    full behavior/vision/audio stack can be developed and tested off-Pi.
    """

    def __init__(self) -> None:
        self._last_angles: dict[int, float] = {}

    def set_angle(self, pin: int, angle_deg: float) -> None:
        self._last_angles[pin] = angle_deg
        logger.debug("MOCK servo pin=%d -> %.1f deg", pin, angle_deg)

    def close(self) -> None:
        logger.debug("MOCK servo backend closed")


class GPIOServoBackend:
    """Real hardware backend using gpiozero.AngularServo.

    Only imports `gpiozero` at construction time so environments without
    the library (or without GPIO access) never fail at module import.
    """

    def __init__(self) -> None:
        from gpiozero import AngularServo  # type: ignore  # local import

        self._AngularServo = AngularServo
        self._servos: dict[int, "AngularServo"] = {}

    def _get_servo(self, pin: int):
        if pin not in self._servos:
            self._servos[pin] = self._AngularServo(
                pin,
                min_angle=0,
                max_angle=180,
                min_pulse_width=0.0005,
                max_pulse_width=0.0025,
            )
        return self._servos[pin]

    def set_angle(self, pin: int, angle_deg: float) -> None:
        servo = self._get_servo(pin)
        servo.angle = max(0.0, min(180.0, angle_deg))

    def close(self) -> None:
        for servo in self._servos.values():
            servo.close()
        self._servos.clear()


def _detect_backend() -> ServoBackend:
    """Return a real GPIO backend if available, else fall back to mock."""
    try:
        return GPIOServoBackend()
    except Exception as exc:  # noqa: BLE001 - broad by design for hw fallback
        logger.info("GPIO servo backend unavailable (%s); using mock.", exc)
        return MockServoBackend()


def ease_toward(current: float, target: float, factor: float) -> float:
    """Move `current` a fraction (`factor`) of the way toward `target`.

    This is a simple exponential ease: each tick covers `factor` of the
    remaining distance, producing smooth deceleration as the target is
    approached. `factor` should be in (0.0, 1.0].
    """
    factor = max(0.0, min(1.0, factor))
    return current + (target - current) * factor


class ServoController:
    """Owns the pan, tilt, and jaw servos and exposes eased movement.

    "Head" naming (update_head / center_head / head_angle) refers
    specifically to the pan (left/right) axis, kept as-is for backward
    compatibility with existing calling code. Tilt (up/down) was added
    afterward as a separate axis with its own eased-movement methods,
    following the same pattern.
    """

    def __init__(self, backend: ServoBackend | None = None) -> None:
        self._backend = backend or _detect_backend()
        self._head_angle = CONFIG.servo.head_center_deg
        self._tilt_angle = CONFIG.servo.tilt_center_deg
        self._jaw_angle = CONFIG.servo.jaw_closed_deg
        # Push initial positions to hardware.
        self._backend.set_angle(CONFIG.pins.head_servo, self._head_angle)
        self._backend.set_angle(CONFIG.pins.tilt_servo, self._tilt_angle)
        self._backend.set_angle(CONFIG.pins.jaw_servo, self._jaw_angle)

    @property
    def head_angle(self) -> float:
        """Current (eased) pan servo angle in degrees."""
        return self._head_angle

    @property
    def tilt_angle(self) -> float:
        """Current (eased) tilt servo angle in degrees."""
        return self._tilt_angle

    @property
    def jaw_angle(self) -> float:
        """Current (eased) jaw servo angle in degrees."""
        return self._jaw_angle

    def update_head(self, target_deg: float, easing_factor: float) -> None:
        """Ease the pan servo one tick toward `target_deg`."""
        clamped = max(
            CONFIG.servo.head_min_deg, min(CONFIG.servo.head_max_deg, target_deg)
        )
        self._head_angle = ease_toward(self._head_angle, clamped, easing_factor)
        self._backend.set_angle(CONFIG.pins.head_servo, self._head_angle)

    def update_tilt(self, target_deg: float, easing_factor: float) -> None:
        """Ease the tilt servo one tick toward `target_deg`."""
        clamped = max(
            CONFIG.servo.tilt_min_deg, min(CONFIG.servo.tilt_max_deg, target_deg)
        )
        self._tilt_angle = ease_toward(self._tilt_angle, clamped, easing_factor)
        self._backend.set_angle(CONFIG.pins.tilt_servo, self._tilt_angle)

    def update_jaw(self, target_deg: float, easing_factor: float = 0.5) -> None:
        """Ease the jaw servo one tick toward `target_deg`."""
        clamped = max(
            CONFIG.servo.jaw_closed_deg,
            min(CONFIG.servo.jaw_open_deg, target_deg),
        )
        self._jaw_angle = ease_toward(self._jaw_angle, clamped, easing_factor)
        self._backend.set_angle(CONFIG.pins.jaw_servo, self._jaw_angle)

    def center_head(self, easing_factor: float) -> None:
        """Ease the pan servo back toward its center resting position."""
        self.update_head(CONFIG.servo.head_center_deg, easing_factor)

    def center_tilt(self, easing_factor: float) -> None:
        """Ease the tilt servo back toward its center resting position."""
        self.update_tilt(CONFIG.servo.tilt_center_deg, easing_factor)

    def close_jaw(self, easing_factor: float = 0.5) -> None:
        """Ease the jaw toward fully closed."""
        self.update_jaw(CONFIG.servo.jaw_closed_deg, easing_factor)

    def shutdown(self) -> None:
        """Release hardware resources."""
        self._backend.close()

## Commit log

2026-08-19 Initial commit: full codebase, OpenSCAD files, docs, build guide
    [electronics_enclosure.scad, electronics_enclosure.stl, eye_led_diffuser.scad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]
2026-08-19 Update docs for Raspberry Pi 4 pivot: torso enclosure, power supply, camera cable routing
2026-08-19 Add pan/tilt servo support and identified_guest recognition wiring
2026-08-19 Pin opencv-contrib-python<5 and playsound==1.2.2 to fix install failures
